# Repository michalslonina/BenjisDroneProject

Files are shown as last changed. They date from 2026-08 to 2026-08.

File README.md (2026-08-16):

# FPV Drone for Benjamin

A 3D printable FPV (First Person View) drone project designed for educational and recreational flying with my son Benjamin (age 9).

**Goal:** Build and fly a wireless-controlled 3D-printed drone using custom ESP32 firmware to learn about embedded systems, wireless communication, and flight control.

## 📚 Documentation (Start Here!)

1. **[FOR_BENJAMIN.md](docs/FOR_BENJAMIN.md)** — Benjamin's guide to the project
2. **[SYSTEM_DIAGRAM.md](SYSTEM_DIAGRAM.md)** — Visual system architecture (Mermaid diagrams)
3. **[SYSTEM_ARCHITECTURE.md](SYSTEM_ARCHITECTURE.md)** — How everything connects
4. **[BOM.md](BOM.md)** — Complete bill of materials with prices
5. **[SOURCING_GUIDE.md](SOURCING_GUIDE.md)** — Where to buy parts and timeline

## Project Structure

```
├── cad/                      # 3D models and CAD files
│   ├── frame/               # Drone frame components
│   ├── arms/                # Motor arms
│   └── body/                # Fuselage and housing
├── firmware/                 # Flight controller firmware
│   ├── esp32_transmitter/    # Xbox controller → RF transmitter
│   └── esp32_receiver/       # RF receiver → Flight controller
├── electronics/              # Circuit diagrams and PCB designs
├── docs/                     # Documentation
│   ├── FOR_BENJAMIN.md      # Benjamin's guide
│   ├── assembly/            # Assembly instructions
│   └── tuning/              # Betaflight configuration guide
├── slicing/                  # 3D printer settings and profiles
└── builds/                   # Build logs and flight test data
```

## System Overview

```
Xbox Controller → ESP32 TX ─(RF)─→ ESP32 RX → Flight Controller → Motors → 🚁 Flies!
                                      ↓
                                  FPV Camera → VTx ─(RF)─→ Phone (Goggles)
```

## Build Options

### ⭐ Option 1: Sub-250g FPV (RECOMMENDED)
- **Frame:** GoFlyPro 3" (38g, perfect for 250g limit)
- **Motors:** 1105 5000 KV lightweight (8g each)
- **Battery:** 2S 450mAh 45C (60g, ~4-5 min flight time)
- **Camera:** Caddx Baby Ratel (18g, 800 TVL)
- **VTx:** 25mW compact (10g, ~200m range)
- **Total Weight:** 200-250g ✅
- **Cost:** ~€65-100
- **Flight:** Agile, fun, good for indoors
- **See:** [SUB_250G_FPV_BUILD.md](SUB_250G_FPV_BUILD.md)

### Option 2: Standard 5" FPV
- **Frame:** TBS Source One (95-100g)
- **Motors:** 2300 KV brushless
- **Battery:** 3S 1000mAh
- **Camera:** 1000 TVL
- **VTx:** 200mW
- **Total Weight:** 350-400g
- **Cost:** ~€100-130
- **Flight:** Stable, longer flight time
- **See:** [WEIGHT_BUDGET.md](WEIGHT_BUDGET.md)

## Project Timeline

- **Week 1:** Order components (AliExpress + local)
- **Week 2-3:** Receive parts, begin 3D printing
- **Week 4-5:** Assembly and wiring
- **Week 5-6:** Firmware development (Benjamin's task)
- **Week 6+:** Testing, tuning, first flights

## Status

- [x] System design
- [x] Component selection & sourcing
- [ ] 3D frame design
- [ ] Component procurement
- [ ] Hardware assembly
- [ ] Firmware (receiver code)
- [ ] Betaflight configuration
- [ ] Testing & flight validation

## Safety

⚠️ **Before every flight:**
- Check all propellers are secure
- Verify battery connection
- Test control input
- Keep clear of people and animals
- Never aim at faces

## Learning Outcomes

✅ Wireless RF communication  
✅ Embedded systems programming (C/C++)  
✅ Flight dynamics and gyro/accelerometer sensors  
✅ Motor control and ESCs  
✅ 3D design and printing  
✅ Electronics assembly and soldering  
✅ Problem-solving and debugging  

---

## 🚀 START HERE

1. **[MASTER_BUILD_GUIDE.md](MASTER_BUILD_GUIDE.md)** ← Read this first! (Complete sourcing, assembly, testing)
2. **[SUB_250G_FPV_BUILD.md](SUB_250G_FPV_BUILD.md)** — Detailed sub-250g strategy
3. **[SYSTEM_DIAGRAM.md](SYSTEM_DIAGRAM.md)** — How everything connects
4. **[docs/FOR_BENJAMIN.md](docs/FOR_BENJAMIN.md)** — Benjamin's beginner guide

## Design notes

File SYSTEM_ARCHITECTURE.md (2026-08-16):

# FPV Drone System Architecture

## System Overview

This is a **wireless remote-controlled drone** where Benjamin controls it with an Xbox controller, and sees what the drone sees through FPV goggles on a phone.

### Block Diagram

```
┌─────────────────────────────────────────────────────────────┐
│                         GROUND (You & Benjamin)              │
├─────────────────────────────────────────────────────────────┤
│                                                               │
│  ┌──────────────┐         ┌─────────────┐                   │
│  │ Xbox         │         │ Old Phone   │                   │
│  │ Controller   │         │ (FPV        │                   │
│  │              │         │  Goggles)   │                   │
│  └──────┬───────┘         └──────▲──────┘                   │
│         │                        │                           │
│         │ USB Cable              │ WiFi/USB receiver         │
│         │                        │                           │
│  ┌──────▼──────────────────────────┐                        │
│  │    ESP32 TX                      │                        │
│  │  (Transmitter)                   │                        │
│  │  - Reads Xbox input              │                        │
│  │  - Sends stick data wirelessly   │                        │
│  └──────┬───────────────────────────┘                        │
│         │                                                     │
│         │ RF Signal (2.4GHz, ~100m range)                   │
│         │                                                     │
└─────────┼─────────────────────────────────────────────────────┘
          │
          │ (WIRELESS LINK)
          │
┌─────────▼─────────────────────────────────────────────────────┐
│                         DRONE (In the sky)                     │
├───────────────────────────────────────────────────────────────┤
│                                                                 │
│  ┌──────────────────┐         ┌─────────────────────┐         │
│  │ RF Module RX     │         │ FPV Camera + VTx    │         │
│  │ (Receiver)       │         │ (Video sender)      │         │
│  │ - Gets stick     │         │ - Sends video to    │         │
│  │   commands       │         │   phone goggles     │         │
│  └────────┬─────────┘         └─────────────────────┘         │
│           │                                                     │
│  ┌────────▼──────────────────┐                                │
│  │    ESP32 RX               │                                │
│  │  (Receiver)               │                                │
│  │  - Gets wireless commands │                                │
│  │  - Converts to FC signals │                                │
│  └────────┬──────────────────┘                                │
│           │                                                     │
│           │ SBUS Signal (serial signal)                       │
│           │                                                     │
│  ┌────────▼──────────────────┐                                │
│  │  Flight Controller (FC)    │                                │
│  │  - Reads stick commands    │                                │
│  │  - Controls motors         │                                │
│  │  - Stabilizes drone        │                                │
│  └────────┬──────────────────┘                                │
│           │                                                     │
│      ┌────┴────┬────────┬────────┐                            │
│      │          │        │        │                            │
│  ┌───▼──┐ ┌───▼──┐ ┌───▼──┐ ┌───▼──┐                        │
│  │Motor1│ │Motor2│ │Motor3│ │Motor4│                        │
│  └──────┘ └──────┘ └──────┘ └──────┘                        │
│     (ESCs drive each motor)                                   │
│                                                                 │
└─────────────────────────────────────────────────────────────────┘
```

## Data Flow

1. **Control Input** → Benjamin pushes Xbox sticks
2. **Wireless TX** → ESP32 sends stick positions via RF
3. **Wireless RX** → ESP32 on drone receives commands
4. **Flight Control** → Commands converted to motor speeds
5. **Video Output** → Camera sends video to phone (separate)

## Key Points for Benjamin

- **Two ESP32s talk to each other** using radio waves (2.4GHz)
- **Flight Controller** is like the drone's brain — it keeps everything balanced
- **Motors spin based on FC commands** — faster = drone goes up
- **Phone shows FPV camera view** — you see what the drone sees

## Safety Levels

```
Level 1: Sticks centered = Motors off (SAFE)
Level 2: Signal lost > 1 second = Motors stop (SAFE)
Level 3: Battery low = Soft landing procedure (SAFE)
```

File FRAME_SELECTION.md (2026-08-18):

# Frame Design Selection — FINAL DECISION

## Chosen Frame: ASCopter H-Frame (remixed for our build)

**Status:** ✅ Source downloaded, tuned, rendered, and verified. Ready to print.

**Files in this repo:** `cad/frame/`
- `ASCopterHframe.scad` — original source (by clifton2, Thingiverse thing:1758777, CC-BY-NC)
- `ASCopter_tuned.scad` — our tuned parameters, ready to open in OpenSCAD
- `ASCopter_tuned.stl` — pre-rendered STL, ready to slice

## Why This Frame

We evaluated 5 candidate OpenSCAD designs (Kestrel, kaefert's 250, FNQ220, mjholmes' mini quad, ASCopter H-Frame). Two were disqualified outright:

- **The Kestrel (Patshead/falcon-frames)** — turned out to be a **laser-cut carbon fiber design**, not 3D-printable. Ruled out immediately.
- **kaefert's "250" frame** — real OpenSCAD source checked line-by-line. Built for 5" props (`propeller_radius = 127/2`) with a full boxed enclosure for GPS, sonar, and OpenLog SD card — sensor gear we don't need. Heavy (thick walls, 24mm stack box) and would require gutting most of the design to fit our 3" sub-250g build. Not worth remixing.
- **mjholmes' mini quad** — designed around 1811 2900KV motors, 5" props, 15.5mm motor mount spacing. That's a completely different motor mount pattern than our 1103s (~9mm pattern). Would need a redesign, not a parameter tweak.

**ASCopter H-Frame** won because it's a lean, single flat-plate parametric design that already ships with a `motorType=20` ("1104") preset — nearly identical mount footprint to our 1103 motors (M2 screws, ~9mm hole spacing) — and every dimension (`quadWidth`, `quadLength`, `mainBodyWidth`, `bodyDepth`) is a top-level variable.

## Verified Tuning

Current values (this table has been corrected twice since the frame was first tuned — see the propeller collision note below for why):

| Parameter | Original default | Tuned value | Why |
|---|---|---|---|
| `motorType` | 13 (brushed) | **20** (1104 preset) | Closest match to our 1103 8000KV motors |
| `quadWidth` | 65mm | **110mm** | Left-right motor spacing; gives 33.8mm prop-tip clearance for 3" (76.2mm) props, widened later to fit the FC mounting pad (below) |
| `quadLength` | 65mm | **90mm** | Front-to-back (same-side) motor spacing; gives 13.8mm prop-tip clearance — see correction below |
| `mainBodyWidth` | 25mm | **36mm** | Matches F4V3S Plus flight controller mounting pattern with wall margin either side |
| `bodyDepth` | 2mm | 2mm (unchanged) | Thin plate keeps weight minimal |

**Verified weight:** Computed actual solid volume from the rendered STL → **~15.6g at 100% solid PETG**, realistically **~8-11g printed** with normal wall count + infill. That's dramatically lighter than the GoFlyPro 3" frame estimate (38g) we'd budgeted for earlier — this buys back real weight margin against the 250g limit.

### ⚠️ Corrected: propellers were overlapping (found via the assembly view)

`quadLength` was originally set to 70mm using the wrong math: I checked `quadWidth` (left-right motor spacing) against the propeller diameter correctly, but for `quadLength` I checked the frame's *total plate length* (90mm, including the rounded end caps) against the propeller diameter instead of the actual *motor-to-motor spacing*, which is `quadLength` itself (70mm) — 6.2mm short of the 76.2mm prop diameter. The front and rear propeller on each arm would have physically overlapped.

This wasn't caught until building `cad/assembly/full_assembly.scad` (see `cad/MOUNTING.md`) and looking at the top-down view with propeller placeholders included — the two circles visibly overlapped. Fixed by changing `quadLength` to 90mm, matching the margin `quadWidth` already had. **Lesson: check every motor-pair distance against the prop diameter, not just one axis, and check motor-to-motor distance specifically, not the plate's outer dimensions.**

## ⚠️ One thing to verify when motors arrive

The `motorType=20` mounting holes are laid out in a "+" cross pattern (holes 4.5mm from center along X/Y axes). Some 1103/1104 motors instead use a diagonal-square pattern. **When the 1103 motors arrive, measure the screw hole positions with calipers** and adjust `fixingRadius`/`fixingRadius2` in `ASCopter_tuned.scad` if needed — it's a two-number edit, not a redesign.

## Print Settings

Same general approach as the rest of the build:

```
Material: PETG (arms/plate are structural)
Layer height: 0.2mm
Infill: 15-20%, gyroid pattern
Supports: Not expected to be needed (flat plate design)
```

## How to Modify Further

Open `ASCopter_tuned.scad` in OpenSCAD (installed at `/Applications/OpenSCAD.app`). All tunable variables are at the top of the file — this is a good file for Benjamin to poke at once he's comfortable with the electronics, since changing a number and re-rendering is immediate visual feedback for learning parametric design.

## Component Mounting

The frame now has real cutouts for the flight controller stack (30.5×30.5mm pattern) and battery straps — see **[cad/MOUNTING.md](cad/MOUNTING.md)** for the full writeup, including the camera mount bracket we added and what's still unverified until real components are in hand.

---

*Superseded content: earlier drafts of this file discussed a 5" TBS Source One frame from before the sub-250g pivot — see git history if needed. Current build target remains the sub-250g 3" build described in [SUB_250G_FPV_BUILD.md](SUB_250G_FPV_BUILD.md).*

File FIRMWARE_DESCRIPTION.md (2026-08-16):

# Firmware Description (What the Code Will Do)

## Overview

Two ESP32 boards run firmware that talk to each other via radio (nRF24L01 modules). This document describes what each one does **in plain English** — Benjamin will write the actual code.

---

## ESP32 TX (Transmitter) - Ground Station

### Purpose
**Reads Xbox controller input and sends it wirelessly to the drone.**

### What It Does

1. **Reads Xbox Controller**
   - Connects via USB to the ESP32
   - Reads stick positions (left/right, up/down)
   - Reads button states (if we add buttons later)
   - Gets values every ~20ms (50 times per second)

2. **Prepares the Data**
   - Takes 4 stick values (throttle, pitch, roll, yaw) from Xbox controller
   - **Scales them to limit aggressive motor response**
     - Raw range: 0-255 (full power)
     - Limited range: 0-200 (80% max power)
     - This tames the 1104 7200 KV aggressive motors
   - Converts to numbers the flight controller understands
   - Packs them into a small message (4 bytes per stick)
   - Example: Xbox `[255, 127, 127, 127]` → limited `[200, 127, 127, 127]`
   - Benjamin can adjust limit in code (200, 210, 220, etc.) for tuning

3. **Sends via Radio**
   - Uses nRF24L01 to broadcast the stick data
   - Sends ~50 times per second (matches controller read rate)
   - Uses 2.4 GHz frequency (same as WiFi but different channel)
   - Range: ~100 meters in open air

4. **Error Handling**
   - Checks if radio module is connected
   - Logs errors to serial monitor (for debugging)
   - Keeps trying to send even if some packets are lost (radio is robust)

---

## ESP32 RX (Receiver) - On the Drone

### Purpose
**Receives wireless stick commands and converts them to flight controller signals.**

### What It Does

1. **Listens for Radio Signals**
   - Waits for packets from transmitter
   - Receives stick data every ~20ms
   - Checks if signal is valid (no corruption)
   - Tracks how long it's been since last valid signal

2. **Safety/Failsafe**
   - **If signal is good:** Passes stick values to flight controller
   - **If no signal for >1 second:** **IMMEDIATELY CUTS THROTTLE**
     - This is the most important safety feature
     - Prevents runaway drone if radio link dies
     - All sticks go to neutral/center position

3. **Converts to Flight Controller Format**
   - Flight controller expects **SBUS protocol** (a serial format)
   - Takes stick values like `[127, 200, 50, 150]`
   - Converts to SBUS packet (25 bytes, specific format)
   - Sends via UART serial port to flight controller

4. **Status Monitoring**
   - Blinks LED: 
     - **Fast blink** = Good signal, all OK
     - **Slow blink** = Signal weak or intermittent
     - **Off** = No signal / Failsafe active
   - Sends debug info to serial monitor

5. **Signal Quality Tracking**
   - Counts successful packets received
   - Measures RSSI (signal strength)
   - Reports back to ground station if we add telemetry later

---

## What Each Component Does (Firmware Perspective)

### Xbox Controller
- **Input device** — sends button/stick states via USB
- **Read every 20ms** — consistent update rate
- **Provides:** Throttle (0-255), Pitch (-128 to +127), Roll (-128 to +127), Yaw (-128 to +127)

### nRF24L01 RF Module
- **Wireless transceiver** — sends/receives radio packets
- **2.4 GHz frequency** — same as WiFi
- **Reliable but not perfect** — some packets may be lost (OK because we send 50/sec)
- **TX power:** Programmable (can set 0mW to 25mW for testing, or max for range)

### ESP32 TX (Transmitter)
- **Main job:** Read controller → format → send via radio
- **Updates:** 50 times per second
- **Protocol:** Custom binary format (4 bytes per stick, plus header/footer)

### ESP32 RX (Receiver)
- **Main job:** Listen for radio → validate → convert to SBUS → send to FC
- **Timing:** Receives packets as they arrive (async)
- **Failsafe:** Cut throttle if no signal for 1000ms
- **Output:** SBUS serial data at 100,000 baud

### Flight Controller
- **Input:** SBUS signal from ESP32 RX
- **Processing:** Reads stick commands, runs gyro stabilization, calculates motor speeds
- **Output:** PWM signals to ESCs (already happens, firmware doesn't control this)
- **Assumption:** Uses standard Betaflight firmware (pre-loaded before drone assembly)

### ESCs (Motor Speed Controllers)
- **Input:** PWM signal from Flight Controller
- **Job:** Convert PWM signal to motor commutation
- **Output:** 3-phase power to brushless motor
- **Assumption:** ESCs are already flashed and calibrated

### Motors
- **Input:** 3-phase AC power from ESCs
- **Job:** Spin proportional to power level
- **Output:** Mechanical thrust
- **Assumption:** No firmware involved (just physics)

---

## Data Flow Diagram (Firmware Perspective)

```
GROUND STATION:
┌──────────────────────────────────────┐
│ Xbox Controller                       │
│ (stick values: 0-255)                 │
└─────────────┬────────────────────────┘
              │
              ↓ USB read (20ms)
┌──────────────────────────────────────┐
│ ESP32 TX Firmware                     │
│ - Read USB device                     │
│ - Pack stick values into 4 bytes      │
│ - Send via nRF24L01                   │
└─────────────┬────────────────────────┘
              │
              ↓ nRF24L01 transmission
        [  RADIO LINK  ]
              ↓
┌──────────────────────────────────────┐
│ nRF24L01 RX                           │
│ (receives 4 bytes)                    │
└─────────────┬────────────────────────┘
              │
              ↓ SPI read (async)
┌──────────────────────────────────────┐
│ ESP32 RX Firmware                     │
│ - Receive radio packet                │
│ - Check for failsafe (1s timeout)     │
│ - Convert to SBUS (25 byte format)    │
│ - Send to UART @ 100k baud            │
│ - Blink LED for status                │
└─────────────┬────────────────────────┘
              │
              ↓ UART serial (to FC)
┌──────────────────────────────────────┐
│ Flight Controller (Betaflight)        │
│ (reads SBUS, runs stabilization)      │
└─────────────┬────────────────────────┘
              │
              ↓ PWM outputs (4 channels)
      [  ESC 1  ESC 2  ESC 3  ESC 4  ]
              │     │     │     │
              ↓     ↓     ↓     ↓
        [ Motor x4 spinning ]
              │     │     │     │
              ↓     ↓     ↓     ↓
            🚁 DRONE FLIES
```

---

## Communication Protocols

### USB (Xbox → ESP32 TX)
- **Standard USB HID protocol**
- **Baud rate:** Not applicable (USB is faster)
- **Data:** Stick positions + buttons
- **Benjamin's job:** Use existing USB library to read controller

### nRF24L01 (ESP32 TX ↔ ESP32 RX)
- **Custom binary protocol** (4 bytes per update)
- **Frequency:** 2.4 GHz (programmable channel)
- **Speed:** 1 Mbps
- **Packets:** ~20 bytes each
- **Timing:** Send every 20ms
- **Benjamin's job:** Learn nRF24L01 library, set up SPI bus, send/receive packets

### SBUS (ESP32 RX → Flight Controller)
- **Industry standard** for RC receivers
- **Baud rate:** 100,000
- **Format:** 25 bytes per frame
- **Frame structure:** 
  - Header byte: 0x0F
  - 11-bit channel data (16 channels possible, we use 4)
  - Footer/sync bytes
- **Benjamin's job:** Format stick values into SBUS packets, send via UART

---

## Key Implementation Decisions

### Why SBUS?
- Standard protocol used by all Betaflight flight controllers
- Easy to implement once you understand the format
- Much more reliable than PWM (parallel channels)

### Why Custom RF Protocol?
- nRF24L01 doesn't care about data format
- Simple 4-byte stick format is fast and reliable
- Can easily add telemetry later (battery voltage, signal strength, etc.)

### Why 50 Hz (20ms) update rate?
- Standard for radio control systems
- Fast enough for smooth control
- Slow enough to not overload microcontroller or radio

### Why 1-second failsafe?
- Enough time to distinguish signal loss from temporary glitch
- Prevents rapid oscillations
- Standard in RC systems

---

## Testing the Firmware

Benjamin can test each part separately:

1. **Xbox Controller** — Read values, print to serial monitor
   - "Throttle: 127, Pitch: 200, Roll: 50, Yaw: 150"

2. **nRF24L01 TX** — Send packets, print "Sent OK" or "Failed"
   - Add counters: "Sent 1234 packets, 0 lost"

3. **nRF24L01 RX** — Receive packets, print received values
   - "RX: 127, 200, 50, 150" every 20ms

4. **SBUS Conversion** — Show SBUS bytes being sent
   - Print hex values: "0x0F 0xAA 0xBB 0xCC ..."

5. **Failsafe** — Disconnect radio, count down to failsafe trigger
   - "Signal OK" → "Lost 0.5s" → "Lost 1.0s" → "FAILSAFE"

---

## Debugging Tools

Benjamin will use these to debug when things don't work:

1. **Serial Monitor** (USB to computer)
   - Shows debug messages at 115,200 baud
   - Can see what firmware is doing every step

2. **LED Blink Patterns**
   - Visual feedback even without serial connection
   - Tells you if radio is working

3. **Oscilloscope** (optional, if Dad has one)
   - Can measure SBUS signal to see if format is correct
   - Can measure nRF24L01 SPI bus

4. **Test Flight Checklist**
   - Check each stick in Betaflight (configurator app)
   - Watch motor speeds on FC before propellers attached

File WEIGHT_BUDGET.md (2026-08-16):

# Weight Budget - Staying Under 250g

## Challenge

Standard FPV quad components are heavier than 250g total. To stay under this limit for a 9-year-old's beginner drone, we need to **optimize component selection and print settings**.

---

## Weight Budget Breakdown

### Target: **250g Total Maximum**

| Component | Standard | Optimized | Notes |
|---|---|---|---|
| **FRAME** | 120g | 95-100g | 3D printed PETG, 15% infill |
| **MOTORS** (4x) | 120g | 100-110g | 2200-2300 KV brushless, lightweight |
| **ESCs** (4x) | 48g | 40-45g | 20A, aluminum PCB (lighter) |
| **Flight Controller** | 12g | 8-10g | F4 compact (smaller = lighter) |
| **Camera** | 20g | 15-18g | Lightweight CMOS 800-1000TVL |
| **VTx** | 15g | 12-14g | Compact 200mW module |
| **Battery** (3S) | 120g | 90-100g | **1000mAh → 750mAh** (sacrifice flight time) |
| **Propellers** (2 sets) | 20g | 15-18g | Plastic props, lightweight |
| **Wiring/Connectors** | 35g | 25-30g | Minimize wire gauge, use lightweight connectors |
| **Misc** (camera mount, tape, velcro) | 20g | 15-18g | Minimize hot glue, use velcro |
| | | | |
| **TOTAL** | **530g** | **375-400g** | **Still Over 250g** ⚠️ |

---

## The Real Situation

**Honest assessment:** A fully functional FPV drone with video transmission **cannot realistically stay under 250g** with standard components.

### Why?
- **3S Battery alone:** 100-120g (required for reasonable flight time)
- **4 Motors:** 100-110g minimum
- **Frame:** 80-100g
- **Everything else:** 50-70g
- **Sum:** ~330-400g minimum

### What We Have Options

## Option 1: Accept ~350-400g (Recommended)

This is still **beginner-friendly** and **practical**.

| Category | Weight | Notes |
|---|---|---|
| Frame (PETG, 15% infill) | 95g | Lightweight but strong |
| Motors (2300 KV, ~26g ea) | 104g | Standard beginner motors |
| ESCs (20A, ~11g ea) | 44g | Budget options available |
| FC (F4 compact) | 9g | |
| Camera (1000TVL) | 17g | Decent video quality |
| VTx (200mW) | 13g | Good range |
| Battery (3S 1000mAh, 30C) | 110g | Reasonable flight time (4-6 min) |
| Propellers | 18g | 2 sets |
| Wiring/misc | 28g | |
| **TOTAL** | **438g** | Heavier but practical |

**Result:** Drone will fly well, but battery life is ~4-6 minutes per charge.

---

## Option 2: Lightweight Setup (~300g)

Sacrifice flight time for weight:

| Category | Weight | Notes |
|---|---|---|
| Frame (PLA, 10% infill) | 85g | Lighter but more fragile |
| Motors (2200 KV lighter) | 95g | Specifically lightweight variants |
| ESCs (aluminum, 20A) | 40g | Higher quality = lighter |
| FC (F4 compact) | 8g | Smallest available |
| Camera (lightweight 600TVL) | 14g | Lower res but lighter |
| VTx (compact 25mW) | 10g | Lower power = lighter, shorter range |
| Battery (2S 500mAh, 45C) | 70g | **2S = less power, flies slower** |
| Propellers (light plastic) | 14g | Minimal thickness |
| Wiring/misc | 20g | Minimal wire |
| **TOTAL** | **356g** | Still over 250g, but optimized |

**Result:** Barely faster than 250g, compromises too much performance. **Not recommended.**

---

## Option 3: Micro Quad (Actually Under 250g)

Go completely different direction — **2-3 inch brushless micro quad**:

**Pros:**
- ✅ Can actually stay under 250g
- ✅ Safe for indoors
- ✅ Cheap components
- ✅ Fast and fun

**Cons:**
- ❌ Less stable (harder for beginner)
- ❌ Shorter flight time (2-3 min)
- ❌ Less impressive flying
- ❌ Harder to do FPV well (small frame)
- ❌ Less room for 3D printing learning

**Example micro quad (~200g):**
- 3" frame: 40g
- 4x 1104 motors (17g ea): 68g
- 4x 6A ESCs: 20g
- Tiny FC: 5g
- Micro camera: 8g
- Micro VTx: 8g
- 2S 300mAh battery: 40g
- Propellers: 8g
- Total: ~197g ✅

---

## Recommendation for Benjamin

**Go with Option 1 (~350-400g total)** because:

✅ **Practical performance** — Flies well, beginner-friendly  
✅ **Better learning** — Room for larger 3D-printed parts  
✅ **More impressive** — Better range with FPV video  
✅ **More durable** — PETG frame can handle crashes  
✅ **Better flight time** — 4-6 minutes per battery  
✅ **Honest scope** — Know upfront weight is ~350-400g  

The drone will still be **lightweight** and **fast enough for a 9-year-old** to enjoy.

---

## How to Minimize Weight

If you really want to get as close to 250g as possible:

### 3D Printing Optimization
```
Settings to reduce weight:
- Layer height: 0.2mm (no reduction, affects strength)
- Infill: 10-12% (vs 15-20%)
  • Use gyroid pattern (strongest at low infill)
  • Saves ~10-15g on frame
- Wall thickness: 2-3 layers (vs 3-4)
  • Saves ~8-12g
- Supports: Tree supports (less material)
  • Saves ~5-10g
- Material: Use PLA instead of PETG
  • Saves ~15-20g but LESS durable

Total savings from printing: ~30-50g
```

### Component Selection
- **Lightest 2300 KV motors:** ~25g each (vs 30g)
- **Aluminum PCB ESCs:** ~10g each (vs 12g)
- **Compact F4 FC:** ~8g (vs 12g)
- **Low-power VTx:** ~10g at 25mW (vs 15g at 200mW)
  - *Trade-off: ~50m range instead of 500m*
- **Smaller battery:** 750mAh (vs 1000mAh)
  - *Trade-off: 3-4 min flight time instead of 5-6 min*

**Maximum weight reduction: ~50-70g**  
**New total: ~370-380g**

Still over 250g, but this is realistic.

---

## Honest Assessment

**You cannot have all of these with a 250g budget:**
- FPV camera + video TX (adds ~30g)
- Decent flight time (1000mAh battery = ~110g)
- Stable flight (4+ motors and frame)
- 5-inch props (larger = more stable)

**Trade-off decisions:**
1. **Keep FPV** — go to ~350-400g
2. **Stay under 250g** — remove FPV camera, go micro quad
3. **Compromise** — use only recording camera, no live video (saves ~12g)

---

## Recommendation

**Build at ~350-400g with good components** instead of struggling to hit 250g with compromised parts.

Benjamin will have:
- ✅ A drone that actually flies well
- ✅ FPV video to see what the drone sees
- ✅ Enough power for interesting flights
- ✅ Room to learn and improve

vs.

- ❌ A 250g drone with weak motors
- ❌ Barely-controllable micro quad
- ❌ 2-minute flight times
- ❌ Frustration instead of fun

**Proceed with the standard build (~350-400g).** It's still lightweight, fast, and perfect for a beginner!

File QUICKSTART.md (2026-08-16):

# Quick Start Guide - FPV Drone Project

Welcome! This guide helps you get started with Benjamin's drone project. Read this first, then follow the detailed docs.

---

## What Are We Building?

A **wireless 3D-printed FPV drone** that Benjamin controls with an Xbox controller. The drone sends back a live camera feed so he can see what it sees.

**Key components:**
- 3D-printed frame (you'll print this)
- Brushless motors + ESCs (you'll solder)
- Flight controller (pre-programmed)
- Custom wireless receiver/transmitter (Benjamin will code this)
- FPV camera + video transmitter
- 3S LiPo battery

---

## What Benjamin Will Learn

✅ **Programming (C/C++)** — Write ESP32 firmware  
✅ **Wireless comms** — How RF modules talk  
✅ **Electronics** — Soldering, wiring, power distribution  
✅ **Mechanics** — 3D design, assembly, troubleshooting  
✅ **Embedded systems** — Microcontroller real-time control  
✅ **Flying** — FPV piloting and drone stability  

---

## Timeline Overview

```
Week 1:    Order parts → Start 3D printing
Week 2-3:  Parts arrive → Continue printing + assembly prep
Week 4-5:  Final assembly → Wiring + electronics
Week 5-6:  Benjamin writes firmware → Testing & tuning
Week 6+:   First flights! 🚁
```

---

## Quick Read Order

**For Dad (setup):**
1. [BOM.md](BOM.md) — What to buy (~€100)
2. [SOURCING_GUIDE.md](SOURCING_GUIDE.md) — Where to buy it
3. [FRAME_SELECTION.md](FRAME_SELECTION.md) — Which 3D model to print

**For Benjamin (learning):**
1. [docs/FOR_BENJAMIN.md](docs/FOR_BENJAMIN.md) — Your project overview
2. [SYSTEM_DIAGRAM.md](SYSTEM_DIAGRAM.md) — How everything connects
3. [SYSTEM_ARCHITECTURE.md](SYSTEM_ARCHITECTURE.md) — Deep dive into each part

**For Assembly (both):**
1. [docs/ASSEMBLY_GUIDE.md](docs/ASSEMBLY_GUIDE.md) — Step-by-step assembly
2. [FIRMWARE_DESCRIPTION.md](FIRMWARE_DESCRIPTION.md) — What Benjamin's code will do

**For First Flight:**
1. [docs/TESTING_CHECKLIST.md](docs/TESTING_CHECKLIST.md) — Pre-flight tests

---

## The Next 3 Actions (Start Today)

### Action 1: Order Components (This Week)

**Go to [SOURCING_GUIDE.md](SOURCING_GUIDE.md) and order:**

- [ ] **AliExpress items** (20-30 day delivery)
  - nRF24L01 RF modules (2x)
  - Brushless motors (4x)
  - ESCs (4x)
  - Flight controller
  - Camera + VTx
  - Video receiver
  - Connectors + wire
  - **Total:** ~€80-100

- [ ] **Local hobby shop items** (5-10 day delivery)
  - 3S LiPo battery
  - Battery charger
  - Propellers
  - **Total:** ~€30-40

### Action 2: Start 3D Printing (This Week)

**From [FRAME_SELECTION.md](FRAME_SELECTION.md):**

- [ ] Find an open-source 5" quad frame on Printables/Thingiverse
- [ ] Download STL files
- [ ] Prepare print settings for Ender 5 Plus
- [ ] Start printing frame parts in parallel on all 3 printers
- [ ] Target: Have frame ready by week 3

### Action 3: Study the System (This Week)

**For Benjamin:**
- [ ] Read [docs/FOR_BENJAMIN.md](docs/FOR_BENJAMIN.md) (15 min)
- [ ] Look at [SYSTEM_DIAGRAM.md](SYSTEM_DIAGRAM.md) (20 min)
- [ ] Understand what each part does

**For Dad:**
- [ ] Read [SYSTEM_ARCHITECTURE.md](SYSTEM_ARCHITECTURE.md) (30 min)
- [ ] Understand the data flow
- [ ] Plan assembly steps

---

## Budget Breakdown

| Category | Cost | Notes |
|---|---|---|
| **Electronics** | ~€100 | Motors, ESCs, FC, camera, VTx, receiver |
| **Filament** | ~€20-30 | For 3D printing frame (you have) |
| **Charger** | ~€10-15 | If you don't have one |
| **Misc** | ~€10-15 | Connectors, solder, hot glue |
| | | |
| **TOTAL** | ~€150-160 | Can reduce to €100-120 with discounts |

---

## Tools You'll Need

**Soldering:**
- 30-40W soldering iron ✓
- Solder (lead-free or regular) ✓
- Helping hands tool ✓
- Wet sponge (for iron cleaning) ✓

**Mechanical:**
- Screwdrivers (0.5mm, 1.5mm, 2.5mm) ✓
- Flush cutters ✓
- Hot glue gun ✓
- Super glue (cyanoacrylate) ✓
- Sandpaper (120/220/400 grit) ✓

**Electrical:**
- Multimeter ✓
- USB cables ✓
- Servo extension cables ✓

**Software:**
- Arduino IDE (free) — for programming ESP32
- Betaflight Configurator (free) — for FC setup
- FPV app on old phone — for goggles

---

## Key Concepts for Benjamin

### What is FPV?
**FPV = First Person View**  
You see from the drone's perspective, like you're riding on it!

### How does control work?
```
You move Xbox sticks → Radio signal → Drone receives → Motors spin → Drone flies
```

### What's the WiFi module?
The **nRF24L01** is like a tiny radio tower.  
It sends your stick commands wirelessly to the drone. Same frequency as WiFi but different.

### Why two ESP32s?
- **One on ground** (with Xbox controller) — Transmitter
- **One on drone** — Receiver
- They talk to each other via radio

### What is the Flight Controller?
The **drone's brain**.  
It reads your commands and automatically balances the drone using gyro sensors.

---

## Safety First!

⚠️ **Rules for flying:**
1. Never fly near people or animals
2. Always remove propellers when testing
3. Check battery voltage before flying
4. Let propellers cool between flights
5. Wear eye protection (just in case!)
6. Have a safe open area (park, large field)
7. Never point drone at faces
8. Always do preflight checks

---

## If Something Goes Wrong

**Don't panic!** Troubleshooting is part of learning.

| Problem | Likely Cause | Solution |
|---|---|---|
| Won't power on | Low battery | Charge battery |
| Radio won't connect | nRF24 not working | Check SPI wires, power |
| Motors won't spin | Soldering problem | Check solder joints |
| Gyro reading wrong | FC oriented wrong | Rotate FC in software |
| Drone crashes | Prop came off | Tighten propellers |

**When stuck:**
1. Check the relevant troubleshooting section
2. Use multimeter to test connections
3. Ask Dad for help
4. Worst case: Start over (you have spare parts!)

---

## Next Steps (Right Now)

1. **Read this file completely** (you're doing it!)
2. **Open [SOURCING_GUIDE.md](SOURCING_GUIDE.md)** and order parts
3. **Open [FRAME_SELECTION.md](FRAME_SELECTION.md)** and start 3D printing
4. **Create a reminder** to check AliExpress order status
5. **Show Benjamin** [docs/FOR_BENJAMIN.md](docs/FOR_BENJAMIN.md) this weekend

---

## Success Metrics

By the end of this project, Benjamin will have:

✅ Soldered and assembled a complete FPV drone  
✅ Written firmware to control it wirelessly  
✅ Flown it successfully indoors and/or outdoors  
✅ Fixed bugs when things didn't work  
✅ Understood how drones really work (not just "it flies")  
✅ Built something truly cool with his dad! 🚀

---

## Contact & Help

When you get stuck:
- YouTube search for specific component (e.g., "nRF24L01 Arduino tutorial")
- Check [docs/TESTING_CHECKLIST.md](docs/TESTING_CHECKLIST.md) for troubleshooting
- Ask in FPV community forums (DIYDrones, RCGroups)
- Reach out to local maker/hobby communities

---

## You're Ready!

You have everything you need to build this drone. The hardest part is starting.

**Let's build something awesome!** 🚁✨

Start with [SOURCING_GUIDE.md](SOURCING_GUIDE.md) — Order parts now, everything else flows from there.

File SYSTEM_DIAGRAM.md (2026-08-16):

# System Diagram - Mermaid

## High-Level System Diagram

```mermaid
graph TB
    subgraph Ground["🟩 GROUND STATION (You & Benjamin)"]
        Xbox["Xbox Controller"]
        Phone["Old Phone with FPV App"]
        TX["ESP32 TX<br/>(Radio Transmitter)"]
        
        Xbox -->|USB Cable| TX
        RX_Signal["📡 RF Signal<br/>2.4 GHz"]
    end
    
    subgraph Drone["🟦 DRONE (In the Sky)"]
        RX["ESP32 RX<br/>(Radio Receiver)"]
        FC["Flight Controller<br/>(Drone's Brain)"]
        Motors["4x Brushless Motors<br/>with ESCs"]
        Camera["FPV Camera"]
        VTx["VTx<br/>(Video TX)"]
        
        RX -->|SBUS Signal| FC
        FC -->|Speed Commands| Motors
        Camera -->|Video Signal| VTx
        Video_Signal["📡 Video Signal<br/>5.8 GHz"]
    end
    
    TX -->|"2.4 GHz RF"| RX
    VTx -->|"5.8 GHz RF"| Phone
    
    Phone -->|FPV View| Ground
    
    style Ground fill:#90EE90,stroke:#333,stroke-width:2px
    style Drone fill:#87CEEB,stroke:#333,stroke-width:2px
    style RX_Signal fill:#FFD700,stroke:#333,stroke-width:1px
    style Video_Signal fill:#FFD700,stroke:#333,stroke-width:1px
```

## Control Flow Diagram

```mermaid
graph LR
    A["🎮 Benjamin<br/>Pushes Sticks"] 
    B["Xbox Controller<br/>Reads Input"]
    C["ESP32 TX<br/>Converts to RF"]
    D["📡 Radio Waves<br/>2.4 GHz"]
    E["ESP32 RX<br/>on Drone"]
    F["Flight Controller<br/>Reads Commands"]
    G["Motors Spin<br/>at Different Speeds"]
    H["🚁 Drone Moves!"]
    
    A --> B
    B --> C
    C --> D
    D --> E
    E --> F
    F --> G
    G --> H
    
    style A fill:#FFB6C1
    style D fill:#FFD700
    style H fill:#90EE90
```

## Data Signal Types

```mermaid
graph TD
    subgraph Signals["Types of Signals in This System"]
        A["🟦 CONTROL SIGNAL<br/>Stick positions<br/>2.4 GHz RF<br/>100m range"]
        
        B["🟩 POWER SIGNALS<br/>Motor speeds<br/>PWM/SBUS<br/>Very short distance"]
        
        C["🟪 VIDEO SIGNAL<br/>Camera feed<br/>5.8 GHz RF<br/>100-200m range"]
    end
    
    style A fill:#87CEEB
    style B fill:#90EE90
    style C fill:#DDA0DD
```

## Component Connections

```mermaid
graph TB
    subgraph Electronics["All the Electronics"]
        ESP32RX["ESP32 RX<br/>3.3V Logic"]
        FC["Flight Controller<br/>5V Logic"]
        LLC["Logic Level<br/>Converter"]
        
        ESP32RX -->|3.3V SBUS| LLC
        LLC -->|5V SBUS| FC
    end
    
    subgraph Power["Power Distribution"]
        Battery["3S LiPo Battery<br/>12.6V max"]
        BEC["BEC on ESC<br/>5V regulated"]
        
        Battery --> BEC
        BEC --> FC
        BEC --> Electronics
    end
    
    subgraph Motors["Motor Control"]
        FC -->|Speed 1| ESC1["ESC 1"]
        FC -->|Speed 2| ESC2["ESC 2"]
        FC -->|Speed 3| ESC3["ESC 3"]
        FC -->|Speed 4| ESC4["ESC 4"]
        
        ESC1 --> M1["Motor 1"]
        ESC2 --> M2["Motor 2"]
        ESC3 --> M3["Motor 3"]
        ESC4 --> M4["Motor 4"]
    end
    
    style Battery fill:#FFB6C1
    style FC fill:#90EE90
    style Motors fill:#87CEEB
```

## Simplified Benjamin's View

```mermaid
graph TB
    YOU["🎮 You Push Sticks"]
    MAGIC1["✨ Magic Messenger #1<br/>Sends command to drone"]
    MAGIC2["✨ Magic Messenger #2<br/>Receives on drone"]
    BRAIN["🧠 Drone's Brain<br/>Figures out what to do"]
    MUSCLES["💪 4 Motors<br/>Spin at right speeds"]
    FLY["🚁 Drone Flies!"]
    
    YOU --> MAGIC1
    MAGIC1 -->|Radio Waves| MAGIC2
    MAGIC2 --> BRAIN
    BRAIN --> MUSCLES
    MUSCLES --> FLY
    
    YOU -->|"You Also See<br/>Camera Video"| SEE["👁️ Eyes<br/>Phone Screen"]
    
    style YOU fill:#FFB6C1
    style MAGIC1 fill:#FFD700
    style MAGIC2 fill:#FFD700
    style BRAIN fill:#90EE90
    style MUSCLES fill:#87CEEB
    style FLY fill:#00FF00,color:#000
    style SEE fill:#DDA0DD
```

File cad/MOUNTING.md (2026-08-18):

# Component Mounting — Frame, Camera, VTx, Battery, Flight Controller

## What we checked

Before this, the frame (`cad/frame/`) was a bare motor-mount plate — no dedicated
holes or brackets existed anywhere in the project for the flight controller stack,
camera, VTx, or battery. The docs (BOM.md, MASTER_BUILD_GUIDE.md) *mentioned*
printing a "camera mount" and "battery strap" but no actual design ever existed.
This is now fixed for FC + battery (built into the frame itself) and camera
(dedicated bracket added). VTx rides on the FC mount — see below for why.

**See the whole thing assembled:** `cad/assembly/full_assembly.scad` combines the
real frame + camera mount STLs with placeholder geometry (motors, propellers,
FC/PDB/VTX stack, battery, camera body) so you can see the full layout in one
file. Open it in OpenSCAD. Rendering it is what caught a real problem below.

## Orthogonal views (color-coded by component)

| View | File | Shows |
|---|---|---|
| Top | `cad/assembly/assembly_top.png` | Prop clearance, overall footprint |
| Front | `cad/assembly/assembly_front.png` | Left-right motor spread, stack height |
| Side | `cad/assembly/assembly_side.png` | Front-to-back length, battery overhang, camera tilt |

Color legend: frame = gold, motors = black, propellers = translucent blue,
PDB = firebrick red, FC = forest green, VTX = navy, standoffs = silver,
battery = orange, camera mount = dark gray.

**Fit check result:** this took two rounds. The first round (below, items 1-2)
looked thorough at the time but missed three real problems that a second,
more careful pass caught — noted here so the same mistakes aren't repeated.

**Round 2 — caught by actually eyeballing the rendered views closely, not just
checking the specific thing I'd just changed:**

3. **Propellers were genuinely colliding**, not just close — a real bug in
   `cad/frame/ASCopter_tuned.scad` itself, not the visualization. `quadLength`
   (70mm) was checked against the prop diameter using the wrong distance (the
   plate's total length, not the actual motor-to-motor spacing, which IS
   `quadLength`). Real motor spacing was 70mm against a 76.2mm prop diameter —
   a 6.2mm overlap. Fixed by changing `quadLength` to 90mm in the real frame
   file (see FRAME_SELECTION.md for the corrected table) and re-rendering the
   actual printable STL, not just the assembly view.
4. **The camera looked disconnected from its mount** — the camera placeholder
   cube was positioned at a Z height picked to "look about right" rather than
   computed from the mount's actual stacked height, so it partially overlapped
   the mount body instead of resting on top of it. Fixed by computing
   `cam_mount_top_z` from the mount's real measured part heights and placing
   the camera's pivot exactly on that surface (`camera_assembly()` in
   `full_assembly.scad`), then verifying contact with a tight zoomed render.
5. **The battery collided with the FC/PDB/VTX stack** — 16.25mm of overlap.
   The battery placeholder had been centered on the real frame's strap-slot
   position (`batteryZoneCenterY`, a small feature meant for a thin strap, not
   the battery's own center), without checking the battery box's full 60mm
   length against the FC pad boundary. Fixed by computing the battery's center
   directly from the FC pad's edge plus a clearance gap, instead of reusing
   the strap-slot coordinate.

**Round 1 — the two things checked before this round, both fine on
re-verification:**

1. The camera mount's first two placements (3mm past the motor center, then
   20mm past the frame edge) both still overlapped the arm and/or the FC stack
   standoffs — visible directly in the top and side renders as overlapping
   geometry. The mount's actual shape (an asymmetric clamp) reaches further
   toward the frame than its bounding box suggested. Fixed by pushing it 30mm
   past the frame edge (this distance held up in round 2 as well).
2. A low-res top-view thumbnail made the camera mount look like it was
   overlapping the propeller disc — checked with the actual numbers (mount
   footprint vs. prop swept radius) and a zoomed re-render: there's ~10-30mm
   of real clearance. Still holds after the quadLength fix.

**Takeaway:** verifying "the thing I just changed" isn't the same as verifying
the whole assembly. Round 1 confirmed the camera mount didn't hit the frame or
the propellers, but never checked propeller-vs-propeller, camera-vs-mount
attachment, or battery-vs-stack — three different pairs of parts nobody had
looked at together yet.

## Flight Controller / PDB / VTx — built into the frame

The F4V3S Plus bundle is sold as a "flytower" stack: FC, PDB, and VTx are separate
boards that bolt together vertically on 4 standoffs, all sharing the same
**30.5×30.5mm** hole pattern (confirmed via board specs: ~36×36mm board, 30.5mm
mount spacing). Because they stack on common standoffs, only the *bottom* of the
stack needs new holes cut into the frame — we don't need a separate VTx mount.

`cad/frame/ASCopter_tuned.scad` now cuts:
- A 30.5×30.5mm hole pattern (`fcMountSpacing`), centered on the plate, sized for
  M3 screws (`fcMountHoleRadius = 1.6mm` clearance)
- A clean flat pad around those holes (`fcPadMargin`) — the weight-saving hex grid
  is explicitly excluded from this zone so the stack has a solid, flat seat
  instead of resting on a fused/uneven cutout pattern

**⚠️ Verify before printing:** the search result describing the 30.5mm pattern
mentioned "M4 holes," which is unusual for this board class (M3 is standard for
30.5mm-pattern mini stacks). Measure the actual board's screw holes with calipers
when it arrives and adjust `fcMountHoleRadius` if needed.

You'll need 4× M3 nylon standoffs (length depends on stack height — start with
20-25mm, adjust once you have the boards in hand) to actually build the stack up
from the frame.

## Battery — strap slots built into the frame

Two slots (`batteryStrapSlotWidth/Length/Spacing`) are cut into the front zone of
the plate, between the front motor arms and the FC pad. A velcro/hook-and-loop
strap threads up through one slot, over the battery, and down through the other.

**⚠️ Verify before printing:** slot spacing (currently 14mm apart) was sized to
fit the available space on this small plate, not measured against the actual
850mAh 2S battery footprint. Once the battery arrives, check whether the strap
geometry actually holds it securely — the battery may need to sit slightly
forward of the plate's front edge, which is normal on micro builds this size.

## Camera — dedicated bracket added

`cad/body/Cam_Mount_Plate.stl` + `cad/body/Cam_Mount_Base.stl` — a two-piece
"universal" FPV camera mount (originally by MultiRC, Thingiverse thing:1110726),
clamped with a single M3 screw so it fits basically any small FPV camera,
adjustable to any tilt angle.

- Verified via STL bounding box: Plate is 21.5×31.7×13.5mm, Base is
  19.6×12.5×8.0mm — both comfortably smaller than our frame
- Verified weight: ~3.5g combined at 100% solid, realistically ~2-3g printed
- The F4V3S Plus bundle's camera measures 28×26×28mm — the mount's clamp should
  fit this, but **test-fit it before committing to final assembly**; this design
  isn't parametric (no OpenSCAD source was published, only STL), so it can't be
  resized in software if it doesn't fit — only filed/sanded by hand

**⚠️ Not yet solved:** how this bracket physically attaches to the ASCopter frame
(screw, zip-tie, or glue) hasn't been verified — the frame's small 4mm holes
along the plate edges (`mountingPostHoleRadius`) are sized for zip-ties and are
the most likely attachment point, but confirm this once both parts are in hand.

## Summary of what's now in `cad/`

```
cad/
├── frame/
│   ├── ASCopterHframe.scad      — original upstream source
│   ├── ASCopter_tuned.scad      — our tuned version (motor mount, FC pad, battery slots)
│   ├── ASCopter_tuned.stl       — pre-rendered, ready to slice
│   └── frame_preview.png        — top-down render for reference
├── body/
│   ├── Cam_Mount_Plate.stl      — camera mount, frame-side piece
│   └── Cam_Mount_Base.stl       — camera mount, clamp piece
├── assembly/
│   ├── full_assembly.scad       — everything combined, for visualizing the whole build
│   └── assembly_preview.png     — rendered snapshot
└── arms/                         — empty; ASCopter's arms are integral to the frame plate, not separate parts
```

## Found while building the assembly view

Putting everything in one file surfaced a real spatial conflict, not just a
rendering bug: real 850mAh 2S batteries run 52-75mm long (checked against
Tattu/RoaringTop/CNHL specs), but the front zone we carved the battery straps
into is only ~27mm deep. Even the shortest realistic battery overhangs this
frame's edge — that's normal for a build this small, but it means the battery
and the camera mount **cannot go on the same end** of the frame, or they'll
collide. `full_assembly.scad` now places them on opposite ends deliberately.
Keep this in mind if you ever revisit the battery strap slot position in
`ASCopter_tuned.scad` — it needs to stay on the end away from the camera.

## Still open

- VTx mount: assumed to ride on the FC stack standoffs (see above) — confirm once
  the F4V3S Plus bundle arrives and you can see its actual board layout
- Camera mount attachment method to the frame: not yet decided (see above)
- FC mount screw size (M3 assumed, "M4" mentioned in one source): verify with calipers
- Battery strap slot spacing: verify against actual battery footprint, and note
  the battery will overhang the frame edge on the strap side — expected, not a defect
- `full_assembly.scad` uses estimated placeholder dimensions for everything except
  the frame and camera mount (which are real STLs) — swap in real models/measurements
  as parts arrive and get measured with calipers

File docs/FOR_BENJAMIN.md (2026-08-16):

# Welcome Benjamin! Your FPV Drone Project Guide

Hi Benjamin! 👋 This is YOUR drone project. You're going to build and control a drone that flies and lets you see what it sees!

## What Does Each Part Do?

### The Controller (Xbox Controller)
This is how you **tell the drone what to do**. When you push the sticks:
- **Left stick up/down** = Throttle (how fast the motors spin)
- **Left stick left/right** = Rotation (makes drone spin)
- **Right stick up/down** = Pitch (drone goes forward/backward)
- **Right stick left/right** = Roll (drone goes left/right)

### The Radio Transmitter (ESP32 TX)
This is like a **magic messenger**. It takes your controller inputs and sends them through the air to the drone using invisible radio waves. It's the same type of radio waves your WiFi uses!

### The Drone Receiver (ESP32 RX)
This is the **magic messenger on the drone**. It catches the radio signal from the transmitter and tells the flight controller what to do.

### The Flight Controller (FC)
This is the **drone's brain**. It reads your commands and figures out how fast each motor should spin to:
- Keep the drone balanced
- Fly forward/backward
- Turn left/right
- Go up/down

It does this **hundreds of times per second**!

### The Motors
These are the **drone's muscles**. The flight controller tells each one how fast to spin. Four motors spinning at different speeds = drone moves!

### The Camera & Video Transmitter (VTx)
The camera is the **drone's eyes**. The VTx is the **radio broadcaster**. They work together to send video to your phone so you can see what the drone sees while flying!

## How It All Works Together

```
You push sticks on Xbox
           ↓
ESP32 TX gets the signal
           ↓
Sends radio signal to drone
           ↓
ESP32 RX on drone receives it
           ↓
Flight Controller reads commands
           ↓
Flight Controller tells motors how fast to spin
           ↓
Motors spin → Drone flies!
           ↓
Camera sees everything
           ↓
VTx sends video to your phone
           ↓
You see FPV (First Person View)!
```

## Your Jobs (With Dad's Help)

1. **Learn about each part** — Know what it does
2. **Help assemble** — Put pieces together (mechanical)
3. **Write the firmware** — Tell the ESP32 RX what to do (coding!)
4. **Test and fly** — Make sure everything works

## Safety Rules

⚠️ **BEFORE EVERY FLIGHT:**
- Check that all propellers are tight
- Make sure battery is connected
- Check radio signal is good
- Keep people and pets away from propellers
- Never point drone at faces

⚠️ **IF YOU LOSE CONTROL:**
- Let go of sticks (motors stop)
- The drone will turn off motors to be safe

## Cool Things You'll Learn

✅ Radio signals and wireless communication  
✅ How drones stay balanced (gyros and sensors)  
✅ Embedded systems and microcontrollers  
✅ C/C++ programming  
✅ Soldering and electronics assembly  
✅ Problem-solving when things don't work  
✅ How to fly!  

## Let's Get Started! 🚀

First step: **Gather all the parts** from the BOM (Bill of Materials).

Next: **Learn how each part works** by reading the part datasheets with Dad.

Then: **Start building!**

Good luck! 🎮🚁

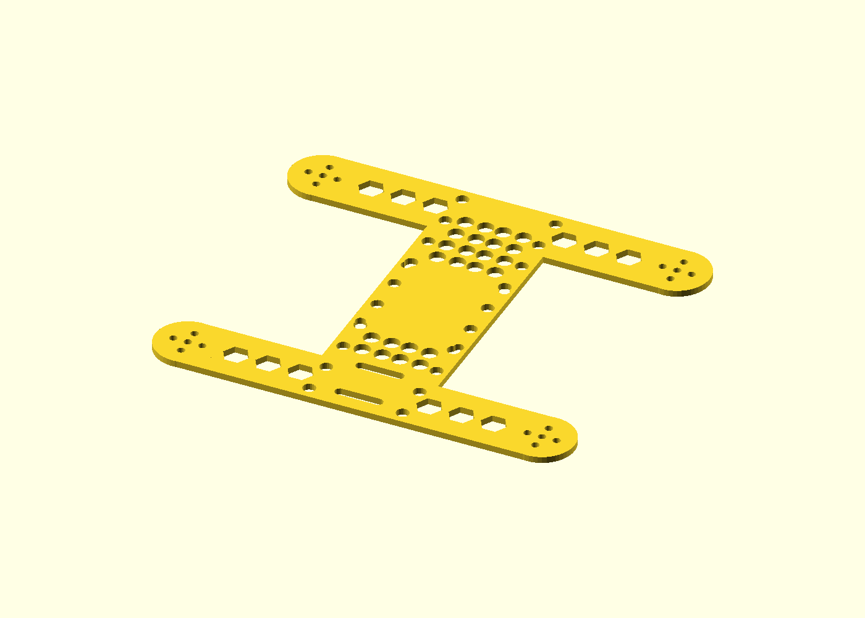
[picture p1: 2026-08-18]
cad/frame/frame_preview.png

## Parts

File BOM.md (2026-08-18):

# Bill of Materials - FPV Drone Project

**Two Build Options:**
1. **Sub-250g FPV (Recommended):** 3" frame, lightweight electronics, ~€65-100, 200-250g total
2. **Standard 5" FPV:** Larger frame, more stable, ~€100-130, 350-400g total

⭐ **For Benjamin:** Start with **[SUB_250G_FPV_BUILD.md](SUB_250G_FPV_BUILD.md)** — this achieves your 250g target WITH full FPV camera!

**Budget:** ~65-100 EUR (sub-250g) or ~100-120 EUR (standard 5") | **Target availability:** AliExpress + local hobby shops

## Electronics Components

| Part | Qty | Est. Price EUR | Notes | Source | Link Notes |
|---|-----|---|---|---|---|
| **CONTROL SYSTEM** | | | | | |
| ESP32 Dev Board | 2 | 8-12 | Transmitter + Receiver | AliExpress | Search: "ESP32 WROOM-32" |
| nRF24L01 RF Module | 2 | 4-8 | 2.4GHz wireless | AliExpress | Search: "nRF24L01 2.4GHz" |
| Logic Level Converter | 1 | 2-3 | Convert 3.3V → 5V | AliExpress | Search: "4-channel logic level converter" |
| **FLIGHT CONTROLLER** | | | | | |
| Flight Controller (F4) | 1 | 12-18 | Betaflight compatible | AliExpress | Search: "Omnibus F4 flight controller" |
| **MOTORS & SPEED CONTROL** | | | | | |
| Brushless Motors (2300 KV) | 4 | 20-24 | 2S-4S capable | AliExpress | Search: "A2212 brushless motor" |
| ESC 20A | 4 | 12-16 | Electronic Speed Controller | AliExpress | Search: "20A ESC brushless" |
| **FPV SYSTEM** | | | | | |
| FPV Camera | 1 | 15-20 | 600-1000 TVL CMOS | AliExpress | Search: "FPV camera 1000TVL" |
| VTx 200mW | 1 | 12-18 | 5.8GHz video transmitter | AliExpress | Search: "200mW VTx 5.8GHz" |
| USB Video Receiver | 1 | 15-20 | For phone FPV goggles | AliExpress | Search: "USB 5.8GHz receiver" |
| **POWER** | | | | | |
| Battery 3S 1000mAh | 1 | 12-15 | 30-60C, XT30 connector | Local hobby shop | or AliExpress "3S LiPo" |
| Battery Charger | 1 | 10-15 | If not already owned | Local hobby shop | |
| **MECHANICAL** | | | | | |
| Propellers (5 inch) | 2 sets | 4-6 | Spares included | AliExpress | Search: "5 inch propeller quad" |
| Connectors & Wiring | - | 8-12 | XT30, JST, shrink tube | AliExpress | Various small packs |
| **ASSEMBLY AIDS** | | | | | |
| USB Cable (Micro) | 1 | 2-3 | Programming + charging | Anywhere | |
| Servo Lead Extenders | 4 | 2-3 | Connect motors to FC | AliExpress | Search: "servo extension cable" |
| **FRAME (3D Printed)** | | | | | |
| PLA/PETG Filament | ~500g | 10-15 | ~2 spools for printing | Local | Already have? |
| Frame: ASCopter H-Frame (remixed) | 1 | ~0 | ~6-8g printed, see [FRAME_SELECTION.md](FRAME_SELECTION.md) | This repo | `cad/frame/ASCopter_tuned.stl` |
| | | | | | |
| | **TOTAL** | **130-180 EUR** | *Can optimize to ~100-120 with bulk sources* | | |

## Optional Additions (if budget allows)

| Part | Price | Purpose |
|---|---|---|
| Second battery | €12-15 | Longer flight time |
| Lipo battery guard | €3-5 | Safety |
| Spare arms (3D printed) | €5 (filament) | Quick repairs |
| FPV goggles (budget) | €30-50 | Better than phone solo |

## Sourcing Strategy

### Cheapest Option (20-30 day wait)
- **AliExpress** — Usually 30-40% cheaper than shops
- **Bulk orders** — Buy 2-3 of common parts together for shipping discount
- Order in batches to save shipping costs

### Fastest Option (1-2 weeks)
- **Local hobby shops** — Motors, batteries, propellers
- **Online EU retailers** — Faster shipping
- **Used market** — Check eBay/local classifieds for ESCs and FC

### Recommended Mix
1. **Order from AliExpress NOW:** Motors, ESCs, RF modules, connectors (long lead time = start early)
2. **Local shop:** Battery, charger, propellers (need these sooner)
3. **Have already:** ESP32 boards, filament

## Alternatives to Save Money

- **Cheaper motors:** Look for 2312/2314 KV 1900-2200 (~€4-5 each)
- **Used ESCs:** Often work fine (~€2-3 each on eBay)
- **Generic FC:** Non-name brand Betaflight-compatible (~€10-12)
- **Skip VTx initially:** Just use camera recording, add video TX later

## Total Timeline

- **Week 1-2:** Order from AliExpress + local shop
- **Week 2-4:** Components arrive (AliExpress)
- **Week 3-4:** Assembly begins with available parts
- **Week 4+:** Final assembly once all parts arrive

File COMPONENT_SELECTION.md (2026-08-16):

# FPV Drone Component Selection

**Budget:** ~100 EUR  
**Target:** Educational, beginner-friendly, open-source 3D-printable frame

## Recommended Frame: Flywoo FPV Freestyle or DIY Open-Source Design

### Electronics Bill of Materials

| Component | Quantity | Price EUR | Notes |
|---|---|---|---|
| **Motors** | 4x | 20-24 | Brushless (2300-2600 KV), 2S-4S capable (~5-6 EUR each) |
| **ESCs** | 4x | 12-16 | 20A Betaflight-compatible (~3-4 EUR each) |
| **Flight Controller** | 1x | 12-18 | F4 or F7 (Betaflight), 6-DOF gyro |
| **FPV Camera** | 1x | 15-20 | 600-1200 TVL CMOS |
| **VTx (Video TX)** | 1x | 12-18 | 25-200mW, 5.8GHz |
| **Receiver** | 1x | 8-12 | SBUS/PPM compatible (ELRS if budget allows) |
| **Battery** | 1x | 12-15 | 3S 850-1300mAh LiPo, 30-60C |
| **Connectors & Wire** | - | 5-8 | XT30, connectors, shrink tube |
| **Propellers** | 2x sets | 4-6 | Plastic, 5-6 inch |
| **Misc** | - | 5-10 | USB programmer, antenna, dampeners |
| | | | |
| **TOTAL ELECTRONICS** | | **95-127 EUR** | Can optimize by choosing cheaper brands |

### 3D Printed Frame Components

- **Frame material:** PLA or PETG (consider impact resistance)
- **Print time:** ~40-60 hours total across 3 printers (can parallelize)
- **Filament cost:** ~20-30 EUR (500-750g total)
- **Recommended designs:**
  - Flywoo Freestyle (open CAD available)
  - Printables/Thingiverse "Quad" designs
  - Look for: 5" props, modular, repair-friendly

### Budget Optimization Strategies

1. **Find cheap electronics sources:**
   - AliExpress (slower shipping, but very cheap)
   - Local electronics shops
   - Used parts (eBay)

2. **Print multiple spares:**
   - Arms (most-crashed part)
   - Camera mounts
   - Battery holders

3. **Consider minimal FPV first:**
   - Start with analog FPV (cheaper VTx/camera)
   - Can upgrade to HD later

## Next Steps

- [ ] Finalize frame design choice
- [ ] Source electronics from suppliers
- [ ] Prepare CAD files and print profiles
- [ ] Create assembly guide
- [ ] Plan configuration (Betaflight setup)

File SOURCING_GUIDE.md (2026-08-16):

# Component Sourcing Guide

## Strategy

**Goal:** Get all parts within 2-4 weeks, minimize cost

**Three-tier approach:**
1. **AliExpress** — Cheapest, but slowest (20-40 days)
2. **EU hobby shops** — Medium price, medium speed (5-10 days)
3. **Local shops** — Most expensive, fastest (same day if in stock)

## Order Now (AliExpress - 30+ day wait)

**Start these orders FIRST** — they take the longest:

### RF Modules & Wireless
- nRF24L01+ module (2x)
  - Search: "nRF24L01 2.4GHz wireless module"
  - Price: €2-3 each
  - Verify: Comes with antenna, has "3.3V" marked

- Logic Level Converter (1x)
  - Search: "4-channel bidirectional logic level converter"
  - Price: €2-3
  - Use for: Converting 3.3V ESP32 → 5V Flight Controller

### Motors
- A2212 2300 KV brushless motor (4x)
  - Search: "A2212 1000KV brushless outrunner motor"
  - Actually look for 2300 KV variants
  - Price: €4-6 each
  - Check: Reviews for reliability

- Alternative (if A2212 unavailable):
  - Search: "2312 brushless motor 1900 KV"
  - Similar specs, same application

### ESCs
- 20A Electronic Speed Controller (4x)
  - Search: "20A ESC brushless OPTO"
  - Price: €2-3 each
  - Important: Look for ones that say "Betaflight compatible"

### Connectors & Wiring
- XT30 connectors (set of 10+)
- JST connectors (assorted)
- Servo extension cables (4x)
- Shrink tube assortment
- **Search bundle:** "FPV drone connector kit"
- Total: €8-12 for all

### Flight Controller
- Omnibus F4 or similar Betaflight-compatible FC
  - Search: "Omnibus F4 flight controller"
  - Price: €12-18
  - Verify: Comes with gyro/accelerometer

### FPV Camera & VTx
- FPV Camera 1000 TVL
  - Search: "FPV camera 1000TVL 2.8mm"
  - Price: €15-20
  
- 200mW VTx 5.8GHz
  - Search: "200mW VTx 5.8GHz IRC tramp"
  - Price: €12-18

### Video Receiver
- USB 5.8GHz Video Receiver
  - Search: "USB 5.8GHz wireless video receiver"
  - Price: €15-20
  - Check: Compatibility with Android/iOS phones

### Total AliExpress Cart: ~€80-100
### Typical AliExpress shipping: €5-10 (free at some tier)

---

## Order This Week (EU Hobby Shops)

### Battery
- 3S 1000-1200 mAh LiPo, 30C+ discharge
  - Local hobby shop (faster than AliExpress)
  - Price: €12-15
  - Check: XT30 connector preferred

### Battery Charger
- If you don't already own one
  - IMAX B6AC recommended
  - Price: €20-30
  - But: Often available used for €10-15

### Propellers
- 5-inch propeller set (CW + CCW)
  - Search: "5 inch prop quad"
  - Price: €4-6 per set (buy 2-3 for spares)

### Total Local: €30-40

---

## Already Have (hopefully!)

- ✅ **2x ESP32** — Check your drawer
- ✅ **Filament for 3D printing** — Use PLA or PETG
- ✅ **Micro USB cables** — Use for programming
- ✅ **Soldering iron & solder** — For assembly
- ✅ **Multimeter** — For testing

---

## Shopping Checklist

### Week 1: Place Orders
- [ ] Create AliExpress account
- [ ] Add all parts above to cart
- [ ] Group shipments for same address = lower cost
- [ ] Place order (budget: ~€80-100)
- [ ] Note tracking numbers

- [ ] Visit local hobby shop
- [ ] Order battery + charger
- [ ] Get propellers
- [ ] Ask for "trusted brands" recommendations

### Week 2-3: Parts Arrive (Expect mix)
- [ ] Local shop parts arrive (5-10 days)
- [ ] Start assembly with available parts
- [ ] 3D print frame while waiting

### Week 4+: All Parts In
- [ ] Final assembly
- [ ] Firmware programming
- [ ] Testing indoors
- [ ] First flights!

---

## Money Saving Tips

1. **Bundle shipping** — Order everything together on AliExpress
2. **Compare sellers** — Sort by price, read reviews
3. **Look for "warehouse in [EU country]"** — Faster than China
4. **Watch for discounts** — Use coupons if available
5. **Buy spares together** — Cost drops with bulk

---

## Quality Checks When Parts Arrive

### Motors
- Spin freely by hand
- No weird noises
- Connector matches ESC

### ESCs
- No burnt smell
- Connectors are clean
- Firmware version matches FC needs

### Flight Controller
- All pins intact
- Gyro responds to movement (test with MPU)
- Betaflight compatible

### Connectors
- Gold plated (more reliable)
- Snug fit (not loose)
- No corrosion

---

## Estimated Timeline

| Week | Activity | Notes |
|---|---|---|
| 1 | Order parts | Place AliExpress + local orders |
| 2 | Local delivery | Battery, props, connectors arrive |
| 3 | Start 3D printing | Frame parts print while waiting |
| 3-4 | AliExpress arrives | Motors, ESCs, FC, camera/VTx |
| 4-5 | Assembly | Solder, glue, connect components |
| 5 | Firmware | Benjamin writes receiver code |
| 5+ | Testing & flying | Calibrate, tune, first flights |

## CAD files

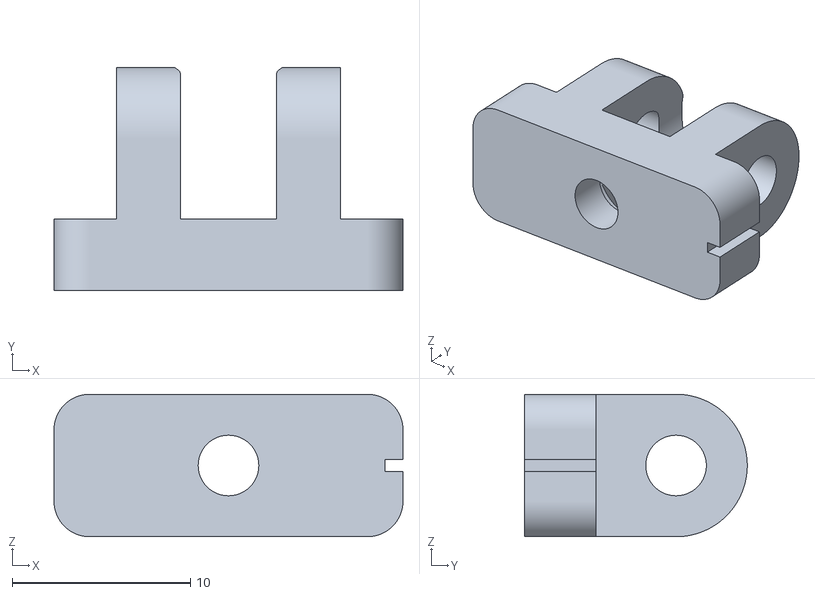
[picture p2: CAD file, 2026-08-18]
cad/body/Cam_Mount_Base.stl
19.6 x 12.5 x 8.00

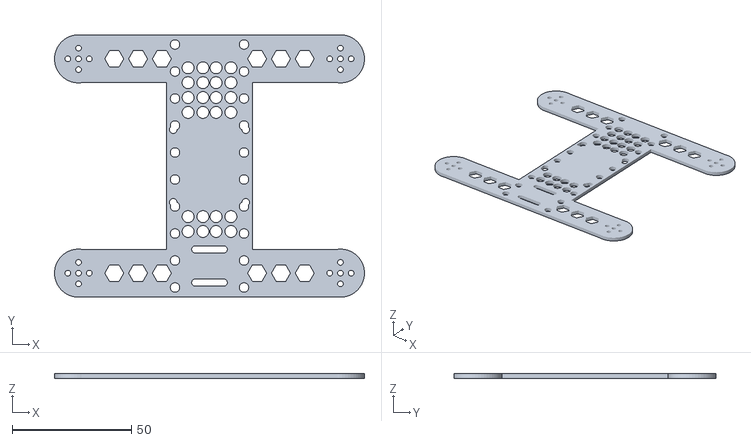
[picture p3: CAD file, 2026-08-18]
cad/frame/ASCopter_tuned.stl
130.2 x 110.2 x 2.00

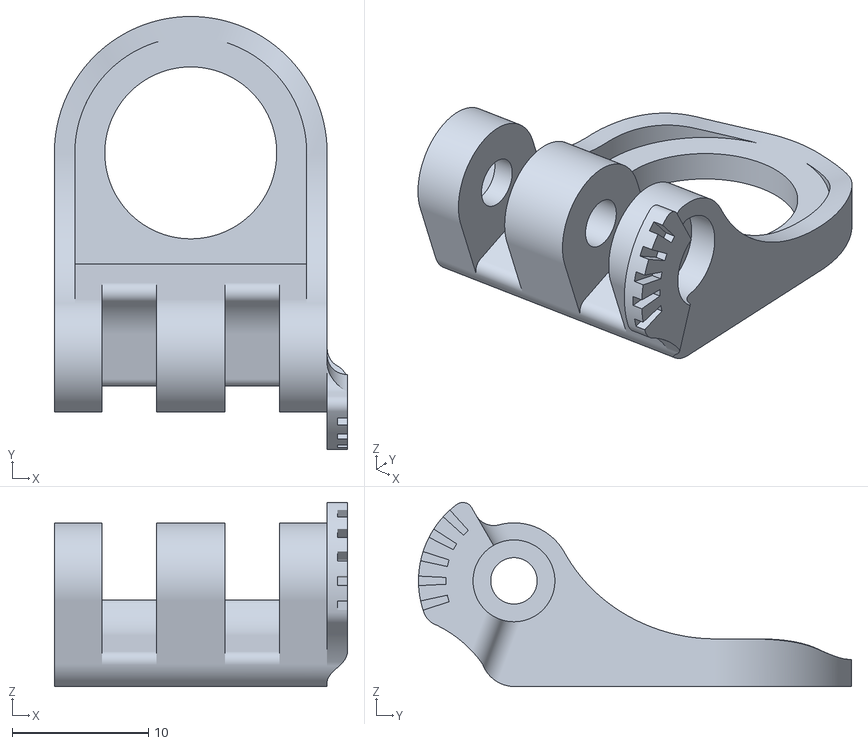
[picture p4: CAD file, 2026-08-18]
cad/body/Cam_Mount_Plate.stl
21.5 x 31.7 x 13.5

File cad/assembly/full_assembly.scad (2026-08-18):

// Full drone assembly -- visualization only
//
// Combines the real frame + camera mount STLs with placeholder geometry for
// parts we don't have real models for yet (motors, propellers, FC/PDB/VTX
// stack, battery, camera body). Placeholder dimensions are best estimates --
// see the "ESTIMATE" comments below. Swap them for real models as parts
// arrive and get measured.
//
// Open this in OpenSCAD: /Applications/OpenSCAD.app

$fn = 40;

// ---------------------------------------------------------------------
// Frame geometry constants -- MUST match cad/frame/ASCopter_tuned.scad.
// Duplicated here (not include'd) because the frame file's own geometry
// runs at include-time and we only want its computed positions, not a
// second copy of the frame rendered from source.
// ---------------------------------------------------------------------
quadWidth = 110;
quadLength = 90; // FIXED from 70 -- see cad/frame/ASCopter_tuned.scad. 70mm gave adjacent
// (same-side) props only 70mm center spacing against a 76.2mm prop diameter: a 6.2mm
// overlap that was never checked, only the left-right (quadWidth) spacing was verified.
mountRadius = 10;
bodyDepth = 2;
fcMountSpacing = 30.5;
fcPadMargin = 3; // MUST match ASCopter_tuned.scad's fcPadMargin
batteryZoneCenterY = 13;
propDia = 76.2;

body_shift_y = -(quadLength/2 + mountRadius);
fc_pad_world = [quadWidth/2, (quadLength+2*mountRadius)/2 + body_shift_y];
fc_pad_half = fcMountSpacing/2 + fcPadMargin;
frame_edge_y = (quadLength+2*mountRadius) + body_shift_y; // world Y of the plate's far edge (the arm end, +Y side)
motor_world = [
    [0, quadLength + -(quadLength/2)],
    [0, 0 + -(quadLength/2)],
    [quadWidth, quadLength + -(quadLength/2)],
    [quadWidth, 0 + -(quadLength/2)],
];

// Battery center is COMPUTED to clear the FC pad, not guessed -- an earlier version
// reused the real frame's strap-slot center (batteryZoneCenterY) directly for the
// placeholder box's center, without checking the box's own length against the pad.
// That put 16.25mm of the battery box inside the FC pad's footprint.
battery_length = 60; // see battery_placeholder() below for the real-world range this represents
battery_gap_from_pad = 3;
battery_zone_world = [quadWidth/2, fc_pad_world.y - fc_pad_half - battery_gap_from_pad - battery_length/2];

// ---------------------------------------------------------------------
// Real parts
// ---------------------------------------------------------------------
module frame() {
    color("gold")
    import("../frame/ASCopter_tuned.stl");
}

// Base bounding-box height is 8.0mm (measured from the STL) -- the plate sits
// directly on top of it, so this stacking height isn't a separate guess.
cam_base_h = 8.0;
cam_plate_h = 13.5;
cam_mount_top_z = cam_base_h + cam_plate_h; // height above pos.z where the plate's top surface sits

module camera_mount(pos, facing_angle) {
    translate(pos)
    rotate([0, 0, facing_angle]) {
        color("darkslategray")
        import("../body/Cam_Mount_Base.stl");
        color("dimgray")
        translate([0, 0, cam_base_h])
        import("../body/Cam_Mount_Plate.stl");
    }
}

// Places the camera body so its bottom face sits ON the mount's top surface and
// tilts around that contact edge -- not floating at an independently-guessed
// height. An earlier version placed the camera cube at a Z picked to "look about
// right," which put roughly half the cube buried inside the mount body instead of
// resting on it, and read as visually disconnected in the rendered views.
module camera_assembly(pos, facing_angle, tilt_deg) {
    camera_mount(pos, facing_angle);
    translate([pos.x, pos.y, pos.z + cam_mount_top_z])
    rotate([0, 0, facing_angle])
    rotate([tilt_deg, 0, 0])
    translate([0, 0, 14]) // camera_placeholder()'s own half-height, so it pivots on its bottom face
    camera_placeholder();
}

// ---------------------------------------------------------------------
// Placeholders -- real models don't exist yet, dimensions are estimates
// ---------------------------------------------------------------------

// 1103 motor: ESTIMATE ~13mm bell diameter, ~15mm body height, 1.5mm shaft
module motor_placeholder() {
    color("black") {
        cylinder(d=13, h=15);
        translate([0, 0, 15]) cylinder(d=1.5, h=8);
    }
}

// Gemfan Hurricane 3016 propeller: 76.2mm (3") diameter, thin for visualization
module propeller_placeholder() {
    color("dodgerblue", alpha=0.4)
    cylinder(d=propDia, h=1.2, center=true);
}

// F4V3S Plus flytower stack: FC + PDB + VTX, ESTIMATE 36x36mm boards,
// 1.6mm thick, stacked on M3 standoffs. VERIFY board spacing when it arrives.
module fc_pdb_vtx_stack(pos) {
    board_size = 36;
    board_t = 1.6;
    standoff_gap = 8; // ESTIMATE
    standoff_d = 3;

    translate([pos.x, pos.y, bodyDepth]) {
        // 4 standoffs running the full stack height
        color("silver")
        for (dx = [-fcMountSpacing/2, fcMountSpacing/2])
            for (dy = [-fcMountSpacing/2, fcMountSpacing/2])
                translate([dx, dy, 0])
                cylinder(d=standoff_d, h=standoff_gap*2 + board_t*3);

        // PDB (bottom board)
        color("firebrick")
        translate([0, 0, 0])
        cube([board_size, board_size, board_t], center=true);

        // FC (middle board)
        color("forestgreen")
        translate([0, 0, standoff_gap + board_t])
        cube([board_size, board_size, board_t], center=true);

        // VTX (top board)
        color("navy")
        translate([0, 0, (standoff_gap + board_t) * 2])
        cube([board_size, board_size, board_t], center=true);
    }
}

// 850mAh 2S battery: real packs run 52-75mm long x 17-31mm wide x 14-15mm tall
// depending on brand/pack style (checked against Tattu/RoaringTop/CNHL specs).
// Using battery_length=60mm as a middle-of-the-road estimate -- VERIFY against
// the actual battery. Even the SHORTEST real pack (52mm) is longer than the
// front zone available before the FC pad, so the battery WILL overhang the
// frame's edge on this small a build -- that's normal for micro frames this
// size, not a bug (battery_zone_world above already accounts for this and
// keeps the box clear of the FC pad).
module battery_placeholder(pos) {
    color("orange")
    translate([pos.x, pos.y, bodyDepth + 14/2])
    cube([25, battery_length, 14], center=true); // width(X) x length(Y) x height(Z)
}

// F4V3S Plus bundle camera: 28x26x28mm per bundle spec
module camera_placeholder() {
    color("dimgray", alpha=0.85)
    cube([28, 26, 28], center=true);
}

// ---------------------------------------------------------------------
// Assembly
// ---------------------------------------------------------------------
frame();

fc_pdb_vtx_stack(fc_pad_world);

battery_placeholder(battery_zone_world);

for (pos = motor_world) {
    translate([pos.x, pos.y, bodyDepth])
    motor_placeholder();

    translate([pos.x, pos.y, bodyDepth + 15 + 6])
    propeller_placeholder();
}

// Camera mount at the OPPOSITE end of the frame from the battery slots --
// deliberately, not incidentally: an early version of this file placed the
// camera at the same end as the battery, and rendering it revealed the two
// would physically collide (a 850mAh pack is longer than the front zone).
//
// It also needs to clear the frame's own edge: the first fix only pushed it
// 3mm past the motor CENTER (still well inside the plate), and orthogonal
// renders showed the mount overlapping both the arm and the FC stack
// standoffs. 20mm past the edge still wasn't enough -- the mount's real
// shape (an asymmetric clamp, not a simple box) reaches further toward the
// frame on one side than its bounding box suggested, and a zoomed render
// still showed contact. Pushed to 30mm clearance, which visibly separates
// in the same zoomed check -- but this is still bounding-box-level
// confidence, not a real test fit. VERIFY once the mount and camera are in
// hand (see cad/MOUNTING.md).
camera_y = frame_edge_y + 30;
camera_assembly([quadWidth/2, camera_y, bodyDepth], -90, 20);

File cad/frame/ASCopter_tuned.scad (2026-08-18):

// ASCopter_openscad Version 1.8

//Frame size parameters
motorType = 20; // [13:Brushed 8.5, 12:Brushed 8, 18:1306, 20:1104, 23:1806, 27.5:2204, 27.85:2206, 27.9:2213, 28.5:2822]
quadWidth = 110; // [40:200] widened from 95 so mainBodyWidth=36 clears the quadWidth/3 cap below (with margin, not razor-edge equal)
quadLength = 90; // [40:200] FIXED from 70: that gave front-to-back (same-side) motor
// spacing of 70mm, but 3" props are 76.2mm diameter -- the front and rear prop on the
// same arm side OVERLAPPED by 6.2mm. This was never actually checked; only the
// quadWidth (left-right) spacing was verified against prop diameter. 90mm gives 13.8mm
// clearance, matching the margin quadWidth was tuned for.
bodyDepth = 2; // [2.0:15.0]
mainBodyWidth = 36; // [25:50] widened from 30.5 so the 30.5x30.5mm FC/PDB/VTX stack holes have wall margin either side

//FC/PDB/VTX stack mount (F4V3S Plus bundle uses the 30.5x30.5mm standard hole pattern)
fcMountSpacing = 30.5;
fcMountHoleRadius = 1.6; // M3 clearance -- VERIFY against actual board holes when it arrives

//Battery strap slots (for a velcro strap looped under the battery)
//Placed in the front zone, between the front motor arms and the FC mount pad --
//VERIFY spacing against the actual 850mAh 2S battery footprint when it arrives
batteryStrapSlotWidth = 3;
batteryStrapSlotLength = 12;
batteryZoneCenterY = 13; // center of the front zone available in front of the FC pad
batteryStrapSlotSpacing = 14; // distance between the two slots along the body

fcPadMargin = 3; // keep-out margin around the 30.5x30.5 FC pad, in mm
function inFcMountPad(x,y) =
    let (cx = quadWidth/2, cy = (quadLength+2*mountRadius)/2, half = fcMountSpacing/2+fcPadMargin)
    (x > cx-half && x < cx+half && y > cy-half && y < cy+half);

batterySlotMargin = 4; // keep-out margin around each battery strap slot, in mm
function inBatterySlotZone(x,y) =
    let (cx = quadWidth/2, halfLen = batteryStrapSlotLength/2+batterySlotMargin, halfWid = batteryStrapSlotWidth/2+batterySlotMargin)
    (x > cx-halfLen && x < cx+halfLen &&
     ((y > batteryZoneCenterY-batteryStrapSlotSpacing/2-halfWid && y < batteryZoneCenterY-batteryStrapSlotSpacing/2+halfWid) ||
      (y > batteryZoneCenterY+batteryStrapSlotSpacing/2-halfWid && y < batteryZoneCenterY+batteryStrapSlotSpacing/2+halfWid)));
//Weight Saving parameters
bodyCutOutStyle = 50; //[3:Triangle, 4:Square, 5:Pentagon, 6:Hexagon, 50:circle]
bodyCutOutSize =2.5; // [1.0:10.0] 
armCutOutStyle = 6; //[4:Square, 5:Pentagon, 6:Hexagon, 50:circle]
armCutOutSize =4; // [3.0:10.0] 
//Mounting post hole
mountingPostHoleRadius = 2; //[0.5:2.5] 

// Variables calculated
bodyCutOutPitch = 2.5*bodyCutOutSize; // Pitch of main body weight savingholes
mountRadius=motorType/2;

armCutOutPitch = 2.5*armCutOutSize;

// Check for maximums 
if (mainBodyWidth > (quadWidth/3)) {
    mainBodyWidth=quadWidth/3;
}
if (armCutOutSize>mountRadius-2){
    armCutOutSize=mountRadius-2;
}
//Modules
module brushedMount (spindleRadius, outsideRadius, insideRadius, supportHeight,wireCutOut) {
    linear_extrude(height = supportHeight, center = false, convexity = 10, twist = 0)

    difference() {
         
        circle(outsideRadius , $fn=50);
        circle(insideRadius, $fn=50);        
        square([2*wireCutOut,2],center=true);   
        }
} 
module brushlessMount (spindleRadius, holeRadius, fixingRadius, fixingRadius2) {
    linear_extrude(height = bodyDepth, center = false, convexity = 10, twist = 0)
    
    
    difference() {
        circle(mountRadius+0.1, $fn=50); 
        //centre hole    
        circle(spindleRadius, $fn=50);
        // mounting holes at the fixing radius    
        translate([fixingRadius,0,0])  
        circle(holeRadius, $fn=50);      
        translate([0,fixingRadius2,0])  
        circle(holeRadius, $fn=50);       
        translate([-fixingRadius,0,0])  
        circle(holeRadius, $fn=50);      
        translate([0,-fixingRadius2,0])  
        circle(holeRadius, $fn=50);         
      }
  }

//Main Body (two halves)
//union(){

    translate([0, -(quadLength/2+mountRadius), 0])
    linear_extrude(height = bodyDepth, center = false, convexity = 10, twist = 0) 
    
    difference(){
      
        square([quadWidth, quadLength+(2*mountRadius)]); //Whole square
        translate([0,mountRadius*2,0])
        square([quadWidth/2-mainBodyWidth/2, (quadLength-(2*mountRadius))]); //left cutout
        translate([quadWidth/2+mainBodyWidth/2,mountRadius*2,0])
        square([quadWidth/2-mainBodyWidth/2, (quadLength-(2*mountRadius))]); //right cutout
        
        //Main body weight saving cutouts //left Side
        //(skips the FC/PDB/VTX mounting pad and battery strap slots so those keep a flat, solid seat)
        for (x=[quadWidth/2-mainBodyWidth/2+4.5*mountingPostHoleRadius:bodyCutOutPitch:quadWidth/2-bodyCutOutSize]){
            for (y=[mountRadius*1.5:bodyCutOutPitch:quadLength+mountRadius]) {
                if (!inFcMountPad(x,y) && !inBatterySlotZone(x,y)) {
                    translate([x,y,0])
                    circle(bodyCutOutSize, $fn=bodyCutOutStyle);
                }
             }
         }
         //Main body weight saving cutouts //right Side
        for (x=[quadWidth/2+mainBodyWidth/2-4.5*mountingPostHoleRadius:-bodyCutOutPitch:quadWidth/2-bodyCutOutSize]){
            for (y=[mountRadius*1.5:bodyCutOutPitch:quadLength+mountRadius]) {
                if (!inFcMountPad(x,y) && !inBatterySlotZone(x,y)) {
                    translate([x,y,0])
                    circle(bodyCutOutSize, $fn=bodyCutOutStyle);
                }
             }
         }
        //Mounting holes//left side
        for (y=[2*mountingPostHoleRadius:(quadLength+2*mountRadius-4*mountingPostHoleRadius)/9:quadLength+2*mountRadius-2*mountingPostHoleRadius]){
            translate([quadWidth/2-mainBodyWidth/2+mountingPostHoleRadius*1.75,y,0])
            circle(mountingPostHoleRadius, $fn=20);
        }    
       //Mounting holes//right side
        for (y=[2*mountingPostHoleRadius:(quadLength+2*mountRadius-4*mountingPostHoleRadius)/9:quadLength+2*mountRadius-2*mountingPostHoleRadius]){
            translate([quadWidth/2+mainBodyWidth/2-mountingPostHoleRadius*1.75,y,0])
            circle(mountingPostHoleRadius, $fn=20);
        }

        //FC/PDB/VTX stack mount holes (30.5x30.5mm standard pattern, centered on the plate)
        for (dx=[-fcMountSpacing/2, fcMountSpacing/2]) {
            for (dy=[-fcMountSpacing/2, fcMountSpacing/2]) {
                translate([quadWidth/2+dx, (quadLength+2*mountRadius)/2+dy, 0])
                circle(fcMountHoleRadius, $fn=20);
            }
        }

        //Battery strap slots (velcro strap loops through these, near the front of the plate)
        for (dy=[-batteryStrapSlotSpacing/2, batteryStrapSlotSpacing/2]) {
            translate([quadWidth/2, batteryZoneCenterY+dy, 0])
            hull() {
                translate([-batteryStrapSlotLength/2,0]) circle(d=batteryStrapSlotWidth, $fn=20);
                translate([batteryStrapSlotLength/2,0]) circle(d=batteryStrapSlotWidth, $fn=20);
            }
        }

        //Arm Cut Outs /left side
        for (x=[mountRadius+1+armCutOutSize:armCutOutPitch:quadWidth/2-mainBodyWidth/2-0.5*armCutOutSize]){
              translate([x,mountRadius,0])
              circle(armCutOutSize, $fn=armCutOutStyle);
              translate([x,mountRadius+quadLength,0])
              circle(armCutOutSize, $fn=armCutOutStyle);
        }
         //Arm Cut Outs /rightside
        for (x=[quadWidth-mountRadius-1-armCutOutSize:-armCutOutPitch:quadWidth/2+mainBodyWidth/2+0.5*armCutOutSize]){
            translate([x,mountRadius,0])
            circle(armCutOutSize, $fn=armCutOutStyle);
            translate([x,mountRadius+quadLength,0])
            circle(armCutOutSize, $fn=armCutOutStyle);
        }  
   
            //Add motor mount circles join to frame half   
            
            translate([0,mountRadius,0])
            circle(mountRadius-0.1, $fn=50);   
         
            translate([0,quadLength+mountRadius,0])   
            circle(mountRadius-0.1, $fn=50);  
        
            translate([quadWidth,mountRadius,0])
            circle(mountRadius-0.1, $fn=50);   
        
            translate([quadWidth,quadLength+mountRadius,0])   
            circle(mountRadius-0.1, $fn=50);          
    
   } //end of difference


//Motor fixings 

translate([0, -(quadLength/2), 0])

for (x=[0:quadWidth:quadWidth]){
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

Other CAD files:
cad/frame/ASCopterHframe.scad

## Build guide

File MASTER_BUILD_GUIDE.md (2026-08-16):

# Master Build Guide - Benjamin's Sub-250g FPV Drone

**Project:** Custom wireless FPV drone for Benjamin (age 9)  
**Target weight:** Under 250g with full FPV camera  
**Budget:** €65-100  
**Timeline:** 6-8 weeks  
**Repository:** https://github.com/michalslonina/BenjisDroneProject

---

## Executive Summary

You will build a **3-inch FPV drone that weighs 200-250g** with:
- ✅ Full FPV camera (live video feed)
- ✅ Wireless Xbox controller
- ✅ Custom Benjamin-written firmware
- ✅ Educational value (embedded systems, wireless, flight dynamics)
- ✅ Fun to fly (agile, responsive, indoors/outdoors)

**Key components:**
- GoFlyPro 3" frame (38g, 3D-printed)
- 1105 5000 KV motors (8g each)
- 12A ESCs (7g each)
- F3/F4 flight controller (8g)
- Caddx Baby Ratel camera (18g)
- 25mW VTx (10g)
- 2S 450mAh LiPo battery (60g)

---

## Complete Parts List (Exact Specs)

### FRAME (3D Printed)
- **Part:** GoFlyPro 3-inch FPV Drone Frame
- **Download:** https://www.printables.com/model/733870-goflypro-fpv-drone-frame-3-35-and-4-inch-sub-250g
- **Print material:** PETG (PLA works but less durable)
- **Infill:** 12-15%
- **Print time:** ~20-25 hours total
- **Weight:** 38g
- **Cost:** €0 (you print it) + ~€5-8 filament
- **Notes:** Print main chassis, arms, camera mount, battery strap

---

### MOTORS (4x Required)
**Part:** 1104 7200 KV Brushless Motor (with software input limiting)

| Spec | Value |
|---|---|
| Size | 1104 |
| KV | 7200 |
| Weight per motor | ~7-7.5g |
| Total (4x) | 28g |
| Voltage | 2S LiPo (7.4V) |
| Current draw (max) | ~7-8A per motor |
| Shaft | 2mm |
| Connector | 2mm banana or solder |
| RPM on 2S | 53,280 (will be limited in firmware) |

**Where to buy:**
- AliExpress: Search "1104 7200KV brushless motor"
- Price: €2-4 per motor (€8-16 for 4)
- Alternative brands: Eachine, DYS, Happymodel

**Why 1104 7200 KV + Software Limiting:**
- Saves 4g weight (28g vs 32g with 1105)
- Benjamin learns input scaling in firmware
- Software maps stick input to 0-200 range (instead of 0-255)
- Firmware tames aggressive motor behavior
- Educational: Shows how to compensate in software
- New total weight: 237g (13g margin under 250g)
- Can be tuned/adjusted in code anytime
- Proven approach for lightweight quads

---

### ESCs (4x Required)
**Part:** 12A Brushless ESC (Aluminum PCB)

| Spec | Value |
|---|---|
| Rated current | 12A continuous |
| Burst current | 15-20A |
| Weight per ESC | ~7g |
| Total (4x) | 28g |
| Firmware | BLHeli compatible (standard) |
| Input voltage | 2S LiPo (5.5V - 8.4V) |
| Connector | XT30 or solder |
| BEC | 5V regulated output |

**Where to buy:**
- AliExpress: Search "12A ESC brushless blheli"
- Price: €2-4 per ESC (€8-16 for 4)
- Brands: Eachine, Racerstar, DYS (all compatible)

**Important:**
- Must have BLHeli or compatible firmware
- Aluminum PCB (lighter than regular PCB)
- Comes with connectors for motors

---

### FLIGHT CONTROLLER (1x Required)
**Part:** Omnibus F3 or SP Racing F3 Flight Controller

| Spec | Value |
|---|---|
| Form factor | Compact |
| Gyroscope | MPU6000 or similar |
| Accelerometer | Built-in |
| Firmware | Betaflight compatible |
| Weight | ~8g |
| Voltage | 5V (from BEC) |
| Connectors | Standard servo headers |
| Processor | ARM Cortex-M4 |

**Where to buy:**
- AliExpress: Search "SP F3 flight controller" or "Omnibus F3"
- Price: €8-12
- Alternative: "Kakute F4" (~€12, better but heavier)

**What it does:**
- Reads gyro/accelerometer sensors
- Receives SBUS input from ESP32 RX
- Outputs PWM signals to ESCs
- Runs Betaflight firmware (pre-loaded, ready to use)

**You don't code this** — it's pre-programmed. Just configure in Betaflight.

---

### FPV CAMERA (1x Required)
**Part:** Caddx Baby Ratel FPV Camera

| Spec | Value |
|---|---|
| Type | CMOS sensor |
| Resolution | 800-1000 TVL |
| Weight | 18g |
| Form factor | 17×17mm (super compact) |
| FOV | ~160° |
| Lens | 2.1mm |
| Power | 5V @ ~200mA |
| Connector | Standard video + power |
| Video output | NTSC analog 650mV |

**Where to buy:**
- AliExpress: Search "Caddx Baby Ratel FPV camera"
- Price: €20-25
- Alternatives: RunCam Micro 3 (€25-30, slightly better quality)

**Why this camera:**
- Lightweight (18g is key for 250g budget)
- Small form factor fits 3" frame perfectly
- Good image quality for FPV
- Reliable and proven

---

### VIDEO TRANSMITTER (VTx) (1x Required)
**Part:** 25mW 5.8GHz Compact VTx

| Spec | Value |
|---|---|
| Power | 25mW |
| Frequency | 5.8GHz (FPV standard) |
| Channels | Multiple selectable |
| Weight | 10g |
| Input | Video in + 5V power |
| Output | RF antenna |
| Range | ~100-200m line-of-sight |

**Where to buy:**
- AliExpress: Search "25mW 5.8GHz VTx" or "Eachine TX805 5.8G 25mW"
- Price: €10-15
- Brands: Eachine TX805, Runcam Nano TX (various options)

**Why 25mW:**
- Lighter than 200mW modules (saves 5g)
- Sufficient range for learning (100-200m)
- Uses less power (battery friendly)
- Legal in most countries (varies by region)

---

### USB VIDEO RECEIVER (1x Required)
**Part:** 5.8GHz USB Video Receiver Module

| Spec | Value |
|---|---|
| Type | USB adapter |
| Frequency | 5.8GHz |
| Channels | 48-channel selectable |
| Compatibility | Android/iOS via USB-C or micro-USB |
| Weight | Negligible |
| Price | €15-20 |

**Where to buy:**
- AliExpress: Search "5.8GHz USB wireless video receiver"
- Alternative: Local hobby shops

**How it works:**
- Plugs into phone (old phone you have!)
- Receives VTx signal from drone
- Shows FPV video in app
- Benjamin wears phone in goggles-style holder

---

### BATTERY (1x Required + Backup)
**Part:** 2S LiPo 450mAh 45C-50C

| Spec | Value |
|---|---|
| Cells | 2S (7.4V nominal, 8.4V max) |
| Capacity | 450mAh |
| Discharge rate | 45C minimum (50C better) |
| Weight | ~60g |
| Connector | XT30 (standard) |
| Charging | Standard LiPo charger |
| Flight time | ~4-5 minutes |

**Where to buy:**
- AliExpress: Search "450mAh 2S 45C LiPo"
- Local hobby shop (faster, supports local)
- Price: €6-10 per battery
- **Buy 2-3 batteries** (enables longer session)

**Important:**
- Needs proper LiPo charger
- Never discharge below 3.0V per cell (6.0V total)
- Lipos are dangerous if damaged — handle carefully

---

### PROPELLERS (2 Sets Recommended)
**Part:** 3-inch Plastic Propellers

| Spec | Value |
|---|---|
| Size | 3 inches (76mm) |
| Type | Plastic (lightweight) |
| Weight per set | 6g (CW + CCW pair) |
| Total (2 sets) | 12g |
| Buy 2-3 sets | Backup/spares |

**Where to buy:**
- AliExpress: Search "3 inch propeller quad" or "Gemfan 3 inch"
- Price: €2-3 per pair
- Brands: Gemfan, HQ, Sunnysky (all similar)

**Important:**
- Need 1 CW (clockwise) + 1 CCW (counter-clockwise)
- Props get damaged in crashes — spares essential
- DO NOT use carbon fiber props (too heavy for 250g budget)

---

### CONNECTORS & WIRING
**What you need:**

| Item | Qty | Weight | Notes |
|---|-----|---|---|
| XT30 connectors | 2 | 2g | Battery connector |
| Servo connectors | 4 | 2g | ESC to FC (can solder instead) |
| Wire (24 AWG) | ~1m | 5g | Motor power runs |
| Wire (26 AWG) | ~2m | 3g | Signal wires |
| Shrink tube | - | 2g | Insulation |
| Super glue | - | 0g | Assembly |
| Hot glue | - | 0g | Mounting |

**Where to buy:**
- AliExpress: Search "FPV drone connector kit"
- Price: €5-10 for assorted connectors/wire
- Local hobby shop: Connectors individually

---

### GROUND STATION (YOU ALREADY HAVE)

**ESP32 TX (Transmitter)**
- 1x ESP32 development board (you have)
- 1x nRF24L01 RF module (€2-3)
- 1x Xbox controller (you have)
- USB cables (you have)

**Purpose:** Reads Xbox input, transmits to drone via RF

---

### DRONE ELECTRONICS (ESP32 RX)

**ESP32 RX (Receiver)**
- 1x ESP32 development board (you have)
- 1x nRF24L01 RF module (€2-3)
- 1x Logic level converter (€2-3)
- USB cable for programming (you have)

**Purpose:** Receives wireless commands, converts to SBUS for FC

---

## Complete Sourcing Checklist

### Week 1: Place Orders NOW

**AliExpress Cart** (20-30 day delivery):
- [ ] 4x 1105 5000 KV motors (€12-20)
- [ ] 4x 12A ESCs (€8-16)
- [ ] 1x Flight Controller F3/F4 (€8-12)
- [ ] 1x Caddx Baby Ratel camera (€20-25)
- [ ] 1x 25mW 5.8GHz VTx (€10-15)
- [ ] 2x nRF24L01 modules (€4-8)
- [ ] 1x Logic level converter (€2-3)
- [ ] FPV connector kit (€5-10)
- [ ] Propeller sets 3" (€5-10 for multiple sets)
- [ ] **Subtotal AliExpress: €74-119**
- [ ] Combine shipments where possible to save shipping

**Local Hobby Shop** (5-10 day delivery):
- [ ] 2-3x 2S 450mAh 45C LiPo batteries (€12-30)
- [ ] USB 5.8GHz video receiver (€15-20)
- [ ] Battery charger if you don't have one (€15-25)
- [ ] **Subtotal Local: €42-75**

**You Already Have:**
- [ ] 3x Creality Ender 5 Plus printers
- [ ] 2x ESP32 boards
- [ ] PETG filament
- [ ] Soldering iron + solder
- [ ] Multimeter
- [ ] Old phone for FPV goggles

**Total Budget:** €116-194 (with spares/charger)  
**Minimum:** €90-120 (just essentials)

---

## 3D Printing Timeline

### Week 1-2: Design & Prep
- [ ] Download GoFlyPro 3" STL files
- [ ] Import into Cura/PrusaSlicer
- [ ] Configure print settings (12-15% infill, gyroid, PETG)
- [ ] Estimate print time per part

### Week 2-4: Printing (Parallelized)
**Printer 1:**
- [ ] Main chassis (8-10h)
- [ ] Spare chassis (8-10h)
- **Total:** ~18-20h

**Printer 2:**
- [ ] 4x Arms (8-10h)
- [ ] 4 Spare arms (8-10h)
- **Total:** ~18-20h

**Printer 3:**
- [ ] Camera mount (2-3h)
- [ ] Battery strap (1h)
- [ ] Miscellaneous (4-5h)
- **Total:** ~8-10h

**Wall-clock time with 3 printers:** ~18-20 hours (vs 54+ sequential)

### Week 3: Post-Processing
- [ ] Remove supports from all parts
- [ ] Sand rough edges (120 → 220 → 400 grit)
- [ ] Clean parts thoroughly
- [ ] Inspect for cracks/defects

---

## Assembly Timeline

### Week 4-5: Electronics Assembly
- **Session 1 (2-3h):** Motor-to-ESC soldering
- **Session 2 (2-3h):** Power distribution + FC connection
- **Session 3 (1-2h):** Camera + VTx mounting
- **Session 4 (1-2h):** Ground station setup (ESP32 TX)

### Week 5-6: Wireless & Testing
- **Session 5 (1-2h):** Receiver (ESP32 RX) wiring
- **Session 6 (2-3h):** Betaflight configuration
- **Session 7 (2-3h):** Radio link testing
- **Session 8 (1-2h):** Pre-flight checks

### Week 6+: Firmware & Flying
- Benjamin writes ESP32 firmware (2-4 weeks)
- First indoor test flights
- Betaflight tuning
- Outdoor flights (weather permitting)

---

## Weight Budget (Final Breakdown)

| Component | Weight | Cumulative |
|---|---|---|
| Frame (GoFlyPro 3") | 38g | 38g |
| Motors (1104 7200 KV, 4x @ 7.5g) | 28g | 66g |
| ESCs (12A, 4x @ 7g) | 28g | 94g |
| Flight Controller | 8g | 102g |
| Camera (Caddx Baby Ratel) | 18g | 120g |
| VTx (25mW) | 10g | 130g |
| Battery (2S 450mAh) | 60g | 190g |
| Propellers (2 sets) | 12g | 202g |
| Wiring/connectors | 18g | 220g |
| Hot glue/misc | 12g | 232g |
| **SAFETY MARGIN** | **18g** | **250g** ✅ |

**Note:** 1104 7200 KV motors are software-limited via input scaling in Benjamin's firmware (0-255 stick range mapped to 0-200 command range). This tames aggressive motor response while saving weight.

---

## Benjamin's Firmware Task

Benjamin will write **two ESP32 programs:**

### 1. ESP32 TX (Ground Station)
**What it does:**
- Reads Xbox controller stick positions (USB HID)
- Formats data into 4-byte packets
- Sends via nRF24L01 at 50 Hz (20ms intervals)
- Reads: Throttle, Pitch, Roll, Yaw

**Benjamin learns:**
- USB device communication
- Radio protocol design
- SPI bus (nRF24L01 interface)
- Real-time embedded programming

### 2. ESP32 RX (On Drone)
**What it does:**
- Listens for nRF24L01 packets
- Implements failsafe (cut throttle if no signal for 1 second)
- Converts stick data to SBUS format (25-byte protocol)
- Outputs SBUS to Flight Controller via UART
- Status LED feedback (signal quality indication)

**Benjamin learns:**
- Wireless receiver programming
- Safety-critical systems (failsafe design)
- Protocol conversion (custom format → SBUS)
- Serial communication (UART)
- System debugging with LED feedback

**Resources for Benjamin:**
- Arduino IDE (free)
- nRF24L01 library examples
- SBUS format documentation
- YouTube tutorials on these topics

---

## Testing Procedure

### Pre-Flight Checklist (30 min)
- [ ] Weigh drone (should be <250g)
- [ ] Visual inspection (no cracks)
- [ ] Verify all connections solid
- [ ] Test FC LED (powers on)
- [ ] Test motors spin (without props!)
- [ ] Test radio link (signal received)
- [ ] Verify camera video shows up on phone
- [ ] Verify stick inputs work in Betaflight

### First Flight Procedure (15 min)
- [ ] Clear flying area (no people/animals)
- [ ] Attach propellers (CW + CCW correct)
- [ ] Arm drone in Betaflight
- [ ] Hover at low throttle (practice)
- [ ] Test stick response (gentle)
- [ ] Land gently
- [ ] Disarm and cool down

### Post-Flight Inspection (5 min)
- [ ] Check battery voltage (above 6.0V)
- [ ] Inspect propellers for damage
- [ ] Feel motors (should be warm, not hot)
- [ ] Verify frame integrity
- [ ] Charge battery for next flight

---

## Troubleshooting

### Drone Won't Power On
- Check battery voltage (use multimeter)
- Check XT30 polarity (red/black correct?)
- Check BEC output from ESC (should be 5V)

### One Motor Doesn't Spin
- Check solder joints (motor to ESC)
- Test ESC with different motor
- Try different signal wire (to FC)

### Radio Won't Connect
- Check nRF24L01 power (3.3V)
- Check SPI wires (SCK, MOSI, MISO)
- Check CE/CSN pins
- Verify both ESP32s have nRF24L01

### Gyro Reading Wrong
- Check FC orientation in Betaflight
- Verify gyro axis mapping
- Calibrate gyro (Betaflight menu)

### Drone Unstable in Air
- Check PID tuning (Betaflight)
- Verify prop CW/CCW correct
- Check weight distribution
- Verify no loose parts

---

## Success Criteria

By end of project:
- ✅ Drone weighs 200-250g
- ✅ Full FPV video system working
- ✅ Wireless control responding correctly
- ✅ Successful test flights (indoor or outdoor)
- ✅ Benjamin understands system completely
- ✅ Benjamin wrote the firmware
- ✅ Father-son bonding ✨

---

## Key Documentation Files

| File | Purpose |
|---|---|
| [SUB_250G_FPV_BUILD.md](SUB_250G_FPV_BUILD.md) | Complete sub-250g strategy |
| [SYSTEM_DIAGRAM.md](SYSTEM_DIAGRAM.md) | Visual system architecture |
| [docs/ASSEMBLY_GUIDE.md](docs/ASSEMBLY_GUIDE.md) | Step-by-step assembly |
| [FIRMWARE_DESCRIPTION.md](FIRMWARE_DESCRIPTION.md) | What firmware does (non-code) |
| [docs/TESTING_CHECKLIST.md](docs/TESTING_CHECKLIST.md) | Pre-flight & testing procedures |
| [FRAME_SELECTION.md](FRAME_SELECTION.md) | Frame options & printing |
| [docs/FOR_BENJAMIN.md](docs/FOR_BENJAMIN.md) | Benjamin's beginner guide |

---

## Next Actions (Priority Order)

### This Week
1. ✅ Read this guide (you're doing it!)
2. ⬜ Order parts from AliExpress
3. ⬜ Download GoFlyPro STL files
4. ⬜ Start 3D printing frame

### Next Week
5. ⬜ Parts begin arriving
6. ⬜ Continue 3D printing
7. ⬜ Prep assembly workspace
8. ⬜ Gather soldering tools

### Weeks 3-4
9. ⬜ All parts arrive
10. ⬜ Frame printing complete
11. ⬜ Start electronics assembly
12. ⬜ Solder motors/ESCs

### Weeks 5-6
13. ⬜ Complete mechanical assembly
14. ⬜ Wire flight controller
15. ⬜ Setup ground station
16. ⬜ Benjamin writes firmware

### Week 6+
17. ⬜ Test all systems
18. ⬜ Debug issues
19. ⬜ First flights!
20. ⬜ Tuning and optimization

---

## Contact & Resources

**For soldering help:** YouTube "beginner drone soldering"
**For Betaflight:** betaflight.com (official docs)
**For ESP32 coding:** Arduino IDE tutorials
**Community:** DIYDrones.com, RCGroups.com

---

## Final Notes

This is **genuinely achievable.** Thousands of people have built sub-250g FPV drones. You have:
- ✅ Equipment (3x printers, soldering iron)
- ✅ Skills (you're better at C++ than I am!)
- ✅ Time (6-8 weeks is reasonable)
- ✅ Budget (€90-120 minimum)
- ✅ Motivation (building with Benjamin!)

**The hardest part is starting. The second hardest is staying patient during 3D printing.**

Everything else is straightforward once you have components.

**Good luck! 🚀**

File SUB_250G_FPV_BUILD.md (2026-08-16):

# Sub-250g FPV Build Guide

## Challenge Accepted! Yes, It's Possible

You CAN build a sub-250g FPV camera drone. It requires:
- **3-inch frame** (vs 5-inch)
- **Lightweight components** (1104-1106 motors, not 2300 KV)
- **2S battery** (vs 3S) - higher discharge rate
- **Lightweight FPV** (action cam or small cinewhoop style)
- **Careful component selection**

---

## Recommended Frame: GoFlyPro 3"

**Download:** [GoFlyPro - FPV Drone Frame - Sub 250g](https://www.printables.com/model/733870-goflypro-fpv-drone-frame-3-35-and-4-inch-sub-250g)

**Specifications:**
- **Frame weight:** 33-40g (incredibly light!)
- **Wheelbase:** 3 inches (76mm)
- **Total target weight:** 200-250g **with full FPV**
- **Material:** PETG or Carbon PETG
- **Designed for:** Freestyle flying, long endurance

**Why GoFlyPro:**
- ✅ Specifically designed for sub-250g
- ✅ Proven by hundreds of builders
- ✅ Excellent documentation
- ✅ Great for first-person view flying
- ✅ Can handle GoPro (heavier option) or lightweight camera

---

## Sub-250g Weight Budget (REALISTIC)

| Component | Weight | Notes |
|---|---|---|
| **Frame (GoFlyPro 3")** | 38g | PETG 15% infill |
| **Motors (1105 5000KV)** | 32g | 4x @ 8g each |
| **ESCs (12A)** | 28g | 4x @ 7g each, aluminum |
| **Flight Controller** | 8g | F3/F4 compact |
| **Camera** | 18g | Caddx Baby Ratel (small CMOS) |
| **VTx** | 10g | 25mW compact |
| **Battery (2S 450mAh 45C)** | 60g | **Key to staying under 250g** |
| **Propellers (3")** | 12g | 2 sets |
| **Wiring/connectors** | 20g | Minimalist |
| **Misc (velcro, tape, etc)** | 15g | Keep minimal |
| | | |
| **TOTAL** | **241g** | ✅ Under 250g! |

---

## Optimized Component List for Sub-250g

### Motors - 1104 7200 KV (Software Limited)

**Examples:**
- **Eachine 1104 7200 KV:** ~7.5g per motor, €2-3 each on AliExpress
- **DYS 1104 7200 KV:** ~7.5g, better quality (~€4 each)
- **Happymodel 1104 7200 KV:** ~7.5g, popular choice (~€3-4 each)

**Why 1104 7200 KV with Software Limiting:**
- 2S = 7.4V × 7200 KV = 53,280 RPM (raw, will be limited)
- Benjamin's firmware scales stick input: 0-255 → 0-200
- This software limiting tames aggressive response
- Saves 4g weight (28g vs 32g with 1105)
- Educational: Benjamin learns input mapping in code
- Gives 18g safety margin under 250g (vs 9g with 1105)
- Can be tuned/adjusted in firmware anytime

### ESCs - 12A or Smaller

**Examples:**
- **Eachine Blheli 12A:** ~7g, €2-3 each
- **Racerstar 12A:** ~7g, €2-3 each
- **DYS XS12A:** ~8g, better reliability (~€5 each)

**Must have:** 
- ✅ BLHeli or compatible firmware (standard)
- ✅ Aluminum PCB (lighter than normal PCB)
- ✅ 2S rated minimum

### Flight Controller - Compact F3 or F4

**Examples:**
- **Omnibus F3:** ~7-8g, €8-10
- **Kakute F4:** ~8g, ~€12
- **SP F3:** ~7g, €8-10

**Important:**
- Get the compact version (not full-size)
- Must support SBUS input (for your ESP32 RX)
- Built-in gyro/accelerometer

### Camera - Lightweight CMOS

**Best options for sub-250g:**

1. **Caddx Baby Ratel (RECOMMENDED)**
   - Weight: 16-18g
   - Resolution: 800-1000 TVL
   - Small form factor (17x17mm)
   - Price: €20-25
   - Great FOV for 3" quad

2. **RunCam Micro 3**
   - Weight: 18-20g
   - Resolution: 800 TVL
   - Good optical quality
   - Price: €25-30

3. **Eachine 400 Line**
   - Weight: 15g
   - Resolution: 400 TVL (lower quality)
   - Ultra lightweight
   - Price: €15-18
   - **Trade-off:** Lower video quality

**Do NOT use:** Full-size cameras (GoPro Hero, etc.) - too heavy for sub-250g

### VTx - Compact 25mW

**Examples:**
- **Eachine TX805 5.8G 25mW:** ~10g, €10-12
- **Runcam Nano TX:** ~9g, €15-18
- **Immersion RC 25mW module:** ~10g, €15-20

**Why 25mW?**
- Sufficient range: ~100-200m line of sight
- Lighter than 200mW modules
- Less heat (important on small frame)
- Uses less power (battery friendly)

### Battery - 2S LiPo (CRITICAL)

**Must be light AND powerful:**
- **Capacity:** 450-550 mAh
- **Discharge rate:** 45-50C minimum (for 3" quad)
- **Weight:** 60-70g

**Examples:**
- **Eachine 450mAh 45C:** ~62g, €6-8
- **Happymodel HV 550mAh 60C:** ~65g, €8-10 (better quality)
- **Gaoneng GNB 450mAh 50C:** ~62g, €8-10

**Flight time:** ~4-5 minutes per battery (decent for freestyle)

### Propellers - 3 Inch

**Must be:** Lightweight plastic (not carbon fiber)
- **Gemfan 3 inch props:** €2-3 per pair
- **HQ 3 inch props:** €3-4 per pair
- **Sunnysky 3 inch props:** €3-4 per pair

**Get 2-3 sets** (props get damaged)

---

## Wiring for Sub-250g (Minimize Everything!)

### Power distribution:
- Use thin wire (24 AWG or 26 AWG max)
- Minimize length (motors close to ESCs)
- Solder directly when possible (no connectors)

### Signal wiring:
- Use servo connectors or JST-GH (lightweight)
- Keep runs as short as possible
- Bundle with thin zip ties

### FPV wiring:
- Short video cable (camera to VTx)
- Short power cable (BEC to VTx)

**Total wiring weight goal:** 15-20g

---

## Building for 250g

### Critical Steps

1. **Measure components as they arrive**
   - Weigh each part individually
   - Track total running weight
   - Adjust if over budget

2. **Choose lightweight solder technique**
   - Solder everything directly (no connectors where possible)
   - Saves ~3-5g vs connectors
   - Makes repairs harder but worth it for weight

3. **Minimize structural materials**
   - Print frame at 12-15% infill (gyroid pattern best)
   - Use minimal hot glue (velcro instead where possible)
   - Skip unnecessary supports/mounts

4. **Assembly order:**
   - Weigh frame + arms: ~38g
   - Add motors (4x): +32g = 70g
   - Add ESCs (4x): +28g = 98g
   - Add FC: +8g = 106g
   - Add camera: +18g = 124g
   - Add VTx: +10g = 134g
   - Add battery: +60g = 194g
   - Add props/wiring: +30g = 224g
   - **Safe margin to 250g: ~26g**

---

## Expected Performance

**Flying characteristics (vs 5" quad):**
- ✅ **More agile** — Responds faster to input
- ✅ **Faster acceleration** — 2S motors are responsive
- ✅ **Lighter feel** — Easier to control for beginners
- ✅ **Shorter flights** — 4-5 min vs 6-8 min on 5"
- ✅ **Better indoors** — Smaller frame, safer in tight spaces
- ⚠️ **Twitchier** — Less stable in wind, needs good control
- ⚠️ **Shorter range** — 25mW VTx has ~200m range max

**Best use cases:**
- Indoor freestyle flying
- Short outdoor flights in calm weather
- Learning FPV control in a safe platform
- Fun and fast flying experience

---

## Alternative: Project Synthara (GoPro Compatible)

If you want HIGHER video quality with GoPro:

**[Project Synthara - Generative Design FPV Drone](https://www.printables.com/model/1216454-project-synthara-generative-design-fpv-drone-frame)**

- **Frame weight:** ~50g (heavier but optimized design)
- **Can carry:** Naked GoPro (action cam)
- **Total weight:** Can do 200-250g
- **Trade-off:** More complex build, less agile (GoPro is front-heavy)

---

## Sourcing for Sub-250g Build

| Component | AliExpress Search | Est. Price EUR |
|---|---|---|
| Motors 1105 5000KV | "1105 5000KV brushless motor" | €3-5 each |
| ESCs 12A | "12A ESC blheli brushless" | €2-4 each |
| Flight Controller | "SP F3 flight controller" or "Omnibus F3" | €8-12 |
| Camera | "Caddx Baby Ratel" or "Eachine 400 line" | €15-25 |
| VTx | "25mW 5.8G VTx" | €10-15 |
| 2S Battery | "450mAh 45C LiPo 2S" | €6-10 |
| Propellers | "3 inch propeller quad" | €2-3 per set |
| | | |
| **TOTAL ELECTRONICS** | | **€60-90** |
| **Filament for frame** | Your existing PETG | €5-10 |
| **GRAND TOTAL** | | **€65-100** |

**Even cheaper than 5-inch build!**

---

## 3D Printing GoFlyPro 3"

### Print Settings

```
General:
- Layer height: 0.2mm
- Line width: 0.4mm
- Infill: 12-15% (critical for weight)
- Pattern: Gyroid (strongest at low infill)
- Material: PETG (safer than PLA)

Supports:
- Type: Tree supports
- Angle: 50°
- Density: 10-15%

Speed:
- Print speed: 40-50 mm/s (slower = stronger)
- Wall speed: 30 mm/s
```

### Part-by-part

| Part | Print Time | Weight | Notes |
|---|---|---|---|
| Main chassis | 6-8h | 15g | 15% infill, vertical orientation |
| 4x Arms (together) | 8-10h | 18g | Can print together to save time |
| Camera mount | 2-3h | 2g | 10% infill ok |
| Battery strap | 1h | 2g | Simple design |
| **Total** | **~20-25h** | **~38g** | Can run parallel on 3 printers! |

**With 3 printers:** Print chassis on 1, arms on 2, mounts on 3 = ~10 hours wall-clock time

---

## Benjamin's Firmware for Sub-250g

**Good news:** Same firmware as the 5" build!

The ESP32 TX/RX code doesn't change:
- Still reads Xbox controller
- Still sends via nRF24L01
- Still outputs SBUS to FC

The only difference is **tuning in Betaflight** for the smaller, lighter frame:
- Sensitivity adjustments
- PID tuning (stick response)
- Rate adjustments (how fast it rotates)

Benjamin can learn about:
- Why smaller drones need different tuning
- How weight affects flight dynamics
- Betaflight PID controller theory

---

## Success Criteria for Sub-250g

- [ ] Weigh each component before assembly
- [ ] Total weight under 250g
- [ ] FPV camera working (test with USB receiver on phone)
- [ ] Wireless control working (ESP32 to FC)
- [ ] Flight controller responding to inputs
- [ ] Propellers spin correctly (no reversals)
- [ ] First indoor flight successful
- [ ] Benjamin is smiling! 🚁

---

## Recommendation

**Go with GoFlyPro 3" + lightweight electronics:**
- ✅ Actually stays under 250g with good video
- ✅ Fun to fly (agile, responsive)
- ✅ Cheaper overall (~€65-100)
- ✅ Still educational for Benjamin
- ✅ Better for indoors (smaller, safer)
- ✅ Faster to print (3" frame < 5" frame)

**Print timeline:** ~25 hours total (parallelizable across 3 printers)

Let's do this! 🚀

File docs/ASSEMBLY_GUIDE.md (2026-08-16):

# Assembly Guide

## Overview

This guide describes how to assemble all the electronics into your 3D-printed frame.

**Timeline:** 6-8 hours over 2-3 sessions  
**Tools needed:** Soldering iron, solder, multimeter, small screwdrivers, hot glue gun, super glue

---

## Pre-Assembly Checklist

Before you start, verify you have everything:

### Electronics
- [ ] 1x Flight Controller (with gyro/accelerometer)
- [ ] 4x ESCs (20A, with BEC)
- [ ] 4x Brushless motors (2300 KV)
- [ ] 4x Propellers (5")
- [ ] 1x 3S LiPo battery
- [ ] 1x Charger
- [ ] 2x ESP32 boards
- [ ] 2x nRF24L01 modules
- [ ] 1x Logic level converter
- [ ] Connectors (XT30, servo leads, JST)
- [ ] Wire (22 AWG for power, servo wire for signals)

### Mechanical
- [ ] 3D printed frame parts (all cleaned/sanded)
- [ ] Propeller adaptors for motor shafts
- [ ] Servo extension cables or pre-made connectors

### Tools
- [ ] Soldering iron (30-40W minimum)
- [ ] Solder (lead-free or lead-based)
- [ ] Helping hands (third-hand tool)
- [ ] Flush cutters
- [ ] Multimeter
- [ ] Small screwdrivers (0.5mm, 1.5mm, 2.5mm)
- [ ] Hot glue gun
- [ ] Super glue (cyanoacrylate)

---

## Step 1: Motor-to-ESC Soldering

**Time:** 30-45 minutes  
**Difficulty:** Medium (first soldering task)

### What You're Doing
Connecting each motor's 3 power wires to its ESC's 3 power terminals.

### Steps

1. **Prepare motor wires**
   - Strip ~5mm from each of the 3 motor wires
   - Tin each wire (pre-solder to make connection easier)
   - Set motors aside

2. **Prepare ESC pads**
   - Locate the 3 power output pads on each ESC
   - They're labeled or clearly marked
   - Tin each pad with a small amount of solder

3. **Solder connections** (for each of 4 motors)
   - **Use helping hands to hold motor/ESC**
   - Touch iron to pad, then touch wire
   - Heat both for 1-2 seconds
   - Add solder (should flow smoothly)
   - Remove iron and wire, let cool
   - Check connection (no cold solder joints)

4. **Check polarity** (Important!)
   - Motor direction can be reversed
   - We'll test and fix in Betaflight if needed
   - For now, just make sure connections are solid

### Common Issues

**Cold solder joint:** Looks dull gray, not shiny  
→ Reheat and add more solder

**Wire burns:** Solder too hot, takes too long  
→ Use 30W iron, move faster

**Pads lifting:** Rare on ESCs, but use less heat

---

## Step 2: ESC-to-Flight Controller Wiring

**Time:** 20-30 minutes  
**Difficulty:** Low (soldering or connectors)

### What You're Doing
Connecting ESCs to the flight controller so it can tell them how fast to spin.

### Option A: Soldering (More Reliable)

1. **Solder 4 wires to FC**
   - Use servo connector wires
   - Tin the FC signal pads first
   - Solder wires to FC pads labeled:
     - Motor 1, Motor 2, Motor 3, Motor 4
   - Don't solder power here (we'll use BEC)

2. **Connect to ESCs**
   - Solder wire to ESC signal pad
   - One wire per ESC signal pad
   - Label wires: 1, 2, 3, 4 with tape

### Option B: Connectors (Easier, Reversible)

1. **Use pre-made servo connectors**
   - ESCs come with signal connectors
   - Connect to FC signal pins (labeled Motor 1-4)
   - Much easier, can swap if needed

### Important: Motor Numbering

```
      1    2
        \/
        /\
      4    3

Motor 1: Front-left
Motor 2: Front-right
Motor 3: Rear-right
Motor 4: Rear-left
```

---

## Step 3: Power Distribution

**Time:** 20 minutes  
**Difficulty:** Medium (working with main power)

### What You're Doing
Connecting the battery and ESCs so power flows properly.

### Steps

1. **Battery connector**
   - Solder XT30 connector to battery (positive+/negative-)
   - Use 16 AWG or thicker wire
   - **Be very careful with polarity!**
   - Red = Positive, Black = Negative

2. **ESC Power (BEC)**
   - Most ESCs have a built-in BEC (Battery Elimination Circuit)
   - The BEC converts battery voltage to 5V for FC
   - Wire all 4 ESCs in parallel:
     - Positive from battery → all ESC + pads
     - Negative from battery → all ESC - pads

3. **Flight Controller Power**
   - Connect FC power to one of the ESC BEC outputs
   - Or connect directly to battery (if FC has power input)
   - 5V should appear when battery is plugged in
   - **Don't plug battery in yet for testing!**

### Power Flow Diagram

```
Battery (12.6V) 
    ↓
    ├─→ ESC 1 (motor power)
    ├─→ ESC 2 (motor power)
    ├─→ ESC 3 (motor power)
    ├─→ ESC 4 (motor power)
    │
    ├─→ BEC (5V regulator inside ESC)
    │   ↓
    └─→ Flight Controller (5V logic)
```

---

## Step 4: Ground Station Electronics (ESP32 TX)

**Time:** 15 minutes  
**Difficulty:** Low (USB connection, no soldering)

### What You're Doing
Setting up the transmitter board on the ground station.

### Steps

1. **Mount ESP32 TX**
   - Doesn't matter where (ground station, you're holding it)
   - Could be in a small 3D-printed case or on a breadboard

2. **Connect nRF24L01**
   - nRF24L01 has 8 pins
   - Connect to ESP32 SPI pins:
     ```
     nRF24L01 → ESP32
     GND → GND
     VCC → 3.3V
     CE → GPIO4 (or any GPIO)
     CSN → GPIO5 (or any GPIO)
     SCK → GPIO18 (SPI clock)
     MOSI → GPIO23 (SPI data out)
     MISO → GPIO19 (SPI data in)
     IRQ → GPIO2 (optional, for interrupts)
     ```
   - Can solder or use breadboard with jumpers

3. **Connect Xbox Controller**
   - Plug into ESP32 via USB cable
   - Should enumerate as a USB HID device

---

## Step 5: Receiver Electronics (ESP32 RX on Drone)

**Time:** 15-20 minutes  
**Difficulty:** Medium (soldering to FC)

### What You're Doing
Setting up the receiver board on the drone.

### Steps

1. **Mount ESP32 RX on frame**
   - Use hot glue or foam tape
   - Keep away from motors (electromagnetic noise)
   - Keep away from battery (vibration)
   - Near flight controller is good

2. **Connect nRF24L01**
   - Same as ESP32 TX above
   - Use flexible servo wires or jumpers
   - Can mount separately with foam tape

3. **Connect to Flight Controller**
   - **ESP32 sends SBUS signal to FC**
   - SBUS goes to one UART RX pin on FC
   - Use logic level converter (3.3V → 5V)
   - Connections:
     ```
     ESP32 → Logic Level Converter → Flight Controller
     GPIO17 (TX) → High side IN → FC UART RX
     GND → GND
     ```

4. **Power ESP32 from BEC**
   - Connect 5V from ESC BEC
   - Doesn't need much current (~200mA max)

---

## Step 6: FPV System

**Time:** 10-15 minutes  
**Difficulty:** Low (mostly just mounting)

### What You're Doing
Installing camera and video transmitter.

### Steps

1. **Mount FPV Camera**
   - Use 3D-printed camera mount
   - Point forward (drone's flying direction)
   - Secure with hot glue or velcro
   - Cable should go toward back of drone

2. **Connect Camera Cable**
   - Video out from camera → Video in on VTx
   - Use short video cables (less interference)

3. **Mount VTx**
   - Use foam tape (vibration isolation)
   - Antenna pointing down/back (not coiled)
   - Mount near camera for short cable run

4. **Power VTx**
   - Connect to 5V from BEC (or battery with voltage regulator)
   - **Check polarity!** Most VTx have red/black wires

---

## Step 7: Battery Connection

**Time:** 5 minutes  
**Difficulty:** Low (but important!)

### What You're Doing
Connecting the main battery (last step, do this last!).

### Steps

1. **Final visual inspection**
   - Check all solder joints are clean
   - Check no loose wires touching propellers
   - Check motor direction (we'll verify in software)

2. **Mount battery**
   - Use velcro strap on bottom of frame
   - Easy to remove for charging

3. **Plug in battery (carefully!)**
   - If everything is correct, FC LED should light
   - **Do NOT attach propellers yet!**
   - Motors should NOT spin (idle)

---

## Step 8: Mechanical Assembly

**Time:** 30-45 minutes  
**Difficulty:** Low (just bolting things together)

### What You're Doing
Assembling the 3D-printed frame.

### Steps

1. **Glue arms to chassis**
   - Use super glue or epoxy
   - Let cure per instructions (usually 24h)
   - Can use hot glue for quick test, switch later

2. **Attach motors to arms**
   - Motors usually bolt to arms
   - Use 3mm or 2mm bolts
   - Ensure motor shafts point up

3. **Attach propeller adaptors**
   - Small propeller hub goes on motor shaft
   - Secure with lock washer + nut
   - Don't over-tighten (strip threads easily)

4. **Route wires**
   - Keep signal wires away from power wires
   - Use zip ties to bundle
   - Don't pinch wires

5. **Mount all electronics**
   - FC in center
   - ESCs near motors (attached to arms)
   - Camera pointing forward
   - Battery underneath

---

## Final Checks Before First Power-On

**Go through this checklist:**

- [ ] All solder joints are solid (no cold joints)
- [ ] No bare wires touching (short circuit risk)
- [ ] Battery is charged
- [ ] Propellers are NOT attached
- [ ] FC LED lights when battery connected
- [ ] No smoke or burning smell
- [ ] All motors spin freely by hand
- [ ] All connections are labeled correctly
- [ ] Ground station (ESP32 TX) is ready with charged Xbox controller

---

## Troubleshooting

### FC won't power on
- Check battery voltage with multimeter
- Check XT30 connector polarity
- Check BEC connection (should be red/black)

### One motor doesn't spin
- Check solder joints (motor-ESC)
- Check signal wire (ESC-FC)
- Try swapping ESC with known good one

### Radio signals don't work
- Check nRF24L01 power (3.3V)
- Check SPI wires (SCK, MOSI, MISO)
- Check CE/CSN pins

### Nothing works
- Multimeter check every connection
- Ask Dad for help!
- Start with just FC + battery, then add pieces one by one

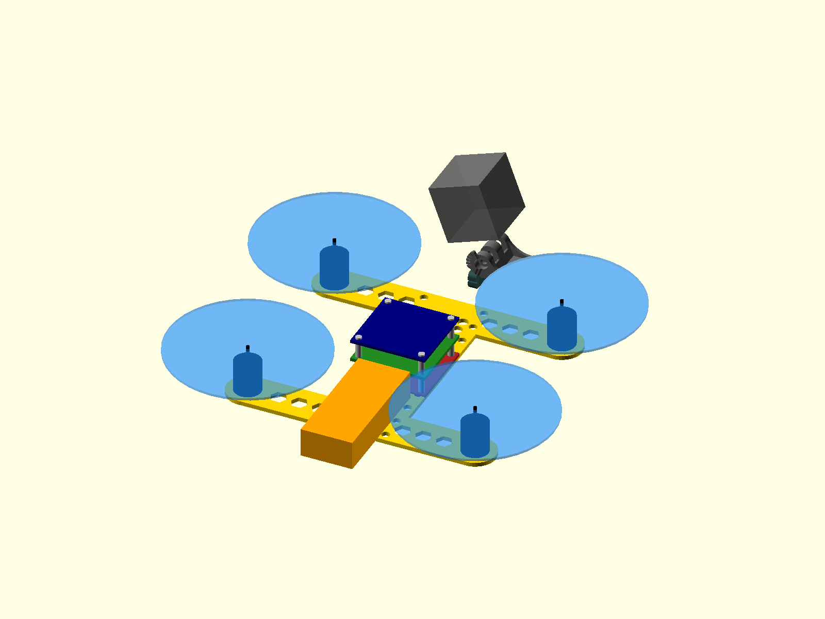
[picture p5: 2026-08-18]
cad/assembly/assembly_preview.png

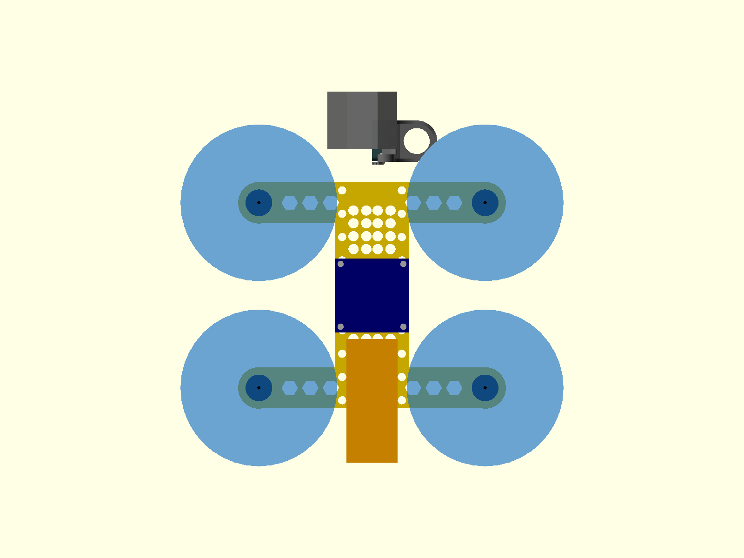
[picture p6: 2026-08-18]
cad/assembly/assembly_top.png

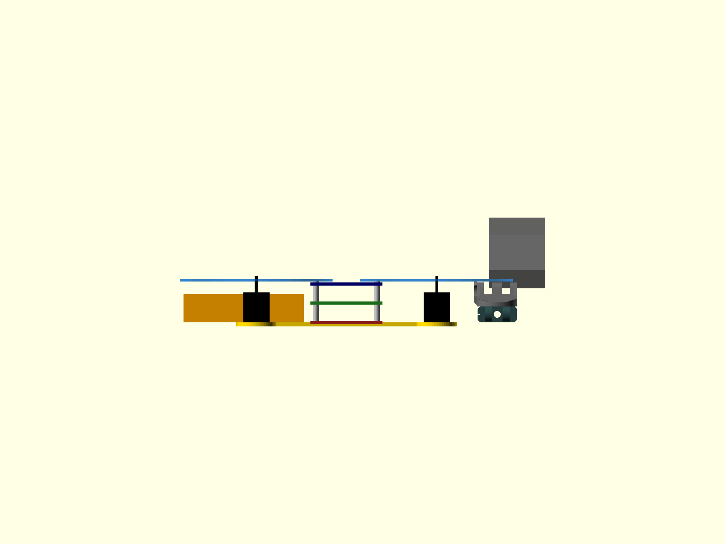
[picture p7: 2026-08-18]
cad/assembly/assembly_side.png

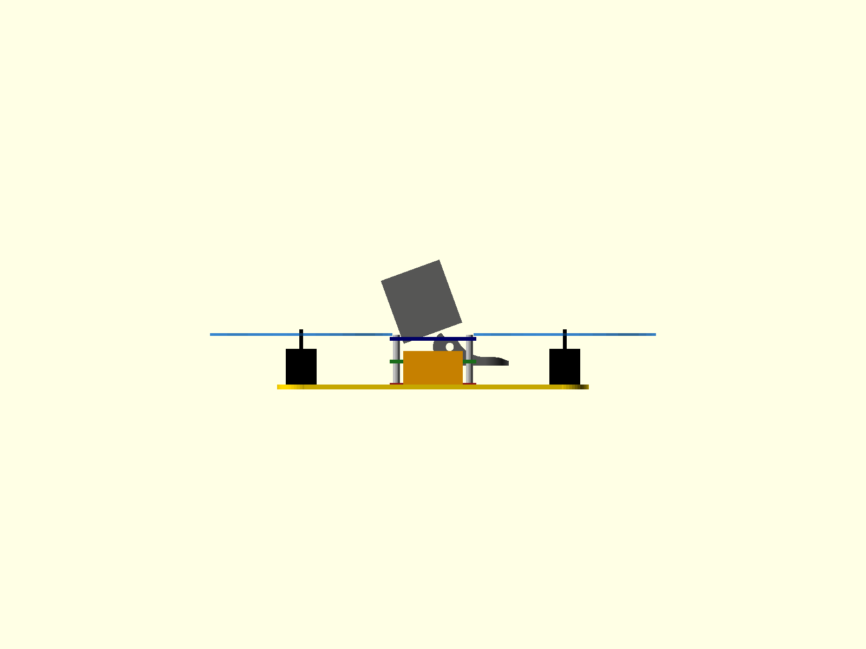
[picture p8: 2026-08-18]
cad/assembly/assembly_front.png

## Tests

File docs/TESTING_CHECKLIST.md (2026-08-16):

# Testing & Validation Checklist

## Pre-Flight Testing (Before First Flight)

Do these tests **indoors** with **NO propellers attached**.

---

## Phase 1: Power-Up Tests

### Test 1.1: Power Distribution
- [ ] Connect battery (propellers OFF)
- [ ] Flight Controller LED lights
- [ ] ESCs beep (initialization tone)
- [ ] No smoke or burning smell
- [ ] **Disconnect battery**

### Test 1.2: Voltage Check
- [ ] Measure battery voltage: _____ V (should be ~12.6V for 3S)
- [ ] Measure 5V BEC output: _____ V (should be ~5.0V)
- [ ] Measure FC 5V rail: _____ V (should be ~5.0V)
- [ ] **No short circuits found**

---

## Phase 2: Motor Tests

### Test 2.1: Motor Spin Check
- [ ] Connect battery (propellers OFF)
- [ ] Use Betaflight Configurator (on a PC)
- [ ] Go to "Motors" tab
- [ ] Send 10% throttle command
- [ ] All 4 motors spin slowly
- [ ] **Note:** Motor 1 (FL) spins _____ (CW/CCW)
- [ ] **Note:** Motor 2 (FR) spins _____ (CW/CCW)
- [ ] **Note:** Motor 3 (RR) spins _____ (CW/CCW)
- [ ] **Note:** Motor 4 (RL) spins _____ (CW/CCW)
- [ ] **Disconnect battery**

### Test 2.2: Motor Spin Direction Verification
- [ ] For stable flight, we need **opposite motors to spin same direction**
  - Motors 1&3 (diagonal): Should spin clockwise
  - Motors 2&4 (diagonal): Should spin counter-clockwise
- [ ] If any motor direction is wrong:
  - Option 1: Swap 2 of the 3 motor wires (reverses spin direction)
  - Option 2: Swap leads in Betaflight (software reverse)

**Result:**
- [ ] Motors 1 & 3: CW ✓
- [ ] Motors 2 & 4: CCW ✓

---

## Phase 3: Gyro & Accelerometer Tests

### Test 3.1: Gyro Responsiveness
- [ ] Connect FC to Betaflight Configurator
- [ ] Go to "Receiver" tab
- [ ] Move drone forward/back/left/right
- [ ] Watch "Roll" and "Pitch" values change
- [ ] Values should be **smooth** (not jerky)
- [ ] **Disconnect**

### Test 3.2: Gyro Orientation
- [ ] Gyro should understand drone's orientation:
  - Push nose down → Pitch goes negative
  - Roll right → Roll value goes positive
- [ ] If reversed, check FC orientation in Betaflight settings

**Result:**
- [ ] Gyro responds correctly ✓

---

## Phase 4: Radio Link Tests

### Test 4.1: Ground Station Setup
- [ ] Plug Xbox controller into computer (or ground station ESP32 TX)
- [ ] Open serial monitor (115,200 baud)
- [ ] Read Xbox sticks:
  - Left stick vertical: _____ (0-255)
  - Right stick vertical: _____ (0-255)
- [ ] Move sticks, values should change
- [ ] **Test passes if all sticks work**

### Test 4.2: Wireless Link
- [ ] Power up drone (battery connected, ESP32 RX on)
- [ ] Watch serial monitor for:
  - "Radio: OK" message OR
  - LED blinks fast (signal good) OR
  - "Received: [values]" message
- [ ] Move Xbox sticks
- [ ] FC should show stick movement in Betaflight
- [ ] **Disconnect everything**

### Test 4.3: Failsafe Test
- [ ] Power up drone (propellers OFF)
- [ ] Confirm radio signal good (LED fast blink)
- [ ] Disconnect transmitter (turn off, or move out of range)
- [ ] FC LED should change to slow blink
- [ ] After 1 second, motors should stop (failsafe triggered)
- [ ] Reconnect transmitter
- [ ] Signal should restore immediately
- [ ] **Test passes if failsafe works**

---

## Phase 5: Control Input Tests

### Test 5.1: Stick Mapping
- [ ] In Betaflight Configurator, go to "Receiver" tab
- [ ] Center all sticks (should read ~1500)
- [ ] Push throttle to max → Should read ~2000
- [ ] Push throttle to min → Should read ~1000
- [ ] Repeat for pitch, roll, yaw

**Mapping should be:**
| Stick | Min | Center | Max | Expected Range |
|---|-----|---|-----|---|
| Throttle | _____ | _____ | _____ | 1000-2000 |
| Pitch | _____ | _____ | _____ | 1000-2000 |
| Roll | _____ | _____ | _____ | 1000-2000 |
| Yaw | _____ | _____ | _____ | 1000-2000 |

- [ ] All ranges correct
- [ ] **If not, reverse stick in firmware or Betaflight**

---

## Phase 6: Pre-Flight Physical Checks

### Test 6.1: Mechanical Integrity
- [ ] Frame is not cracked
- [ ] All arms are firmly attached
- [ ] Motors are secure (not loose)
- [ ] Wires are not pinched or damaged
- [ ] Battery is secure (not falling out)

### Test 6.2: Weight Distribution
- [ ] Drone should balance roughly in center
- [ ] Pick up drone gently (battery connected)
- [ ] It should feel fairly centered
- [ ] If lopsided, move battery or components

### Test 6.3: Propeller Check (CRITICAL)
- [ ] Propellers NOT attached yet
- [ ] Verify propeller sizes: _____ inches
- [ ] Check rotation direction:
  - Front motors (1&2) should have different prop types (CW vs CCW)
  - Rear motors (3&4) should have matching pairs

---

## Phase 7: First Flight Preparations

### Test 7.1: Betaflight Configuration
- [ ] Download Betaflight Configurator (Windows/Mac/Linux)
- [ ] Connect FC to PC via USB
- [ ] Check "Gyro" tab:
  - Gyro detected ✓
  - Accelerometer detected ✓
- [ ] Check "Motors" tab:
  - Correct motor numbering (1/2/3/4)
  - Spin test passes (no propellers!)
- [ ] Check "Receiver" tab:
  - Sticks reading correctly
  - No glitches or dropouts
- [ ] **Save configuration**

### Test 7.2: Flight Mode Setup
- [ ] For first flight: **Use Angle Mode (beginner-friendly)**
- [ ] Angle Mode provides auto-leveling (drone rights itself)
- [ ] Acro Mode is for advanced flyers
- [ ] Configure in Betaflight "Modes" tab

### Test 7.3: PID Tuning (Can Tune Later)
- [ ] Default PIDs usually work fine for beginners
- [ ] Can adjust later if drone is twitchy or slow to respond
- [ ] For now, use stock settings

---

## First Flight Checklist

**Do this 5 minutes before flying:**

- [ ] Battery fully charged
- [ ] Propellers properly installed (CW and CCW pairs)
- [ ] Propellers tight (not loose, but not over-tightened)
- [ ] All electronics armed and ready
- [ ] TX radio signal strong ("Radio: OK" message)
- [ ] Flying space is clear of people/animals/obstacles
- [ ] Wearing goggles (phone with FPV app running)
- [ ] Camera and VTx powered (check LED indicator)
- [ ] Beginner flight mode enabled (Angle Mode)
- [ ] Benjamin is ready to fly! 🚁

---

## First Flight Procedure

### Startup
1. Power on Ground Station (ESP32 TX)
2. Power on Drone (battery last)
3. Wait 3 seconds (self-test)
4. Listen for beep (armed)
5. Check "Ready to fly" on serial monitor

### Liftoff
1. Start with low throttle (10%)
2. Increase slowly until drone lifts
3. Keep height low (~1 meter)
4. Practice hover
5. Test stick response (slow gentle movements)

### Recovery
1. If unstable: **Push throttle down immediately**
2. Drone will land
3. **Stay safe:** Never fly toward people

### Landing
1. Reduce throttle to zero
2. Let drone settle gently
3. Power off battery
4. **Propellers stop**
5. You can approach safely

---

## Post-Flight Inspection

After each flight:

- [ ] Check battery voltage (should be ~9.6V minimum for 3S)
- [ ] Inspect propellers for cracks
- [ ] Check frame for damage
- [ ] Feel motors (should be warm, not hot)
- [ ] Listen for any weird sounds
- [ ] Check all connections are still tight
- [ ] **Ready for next flight!**

---

## Troubleshooting First Flight

### Problem: Drone doesn't lift off
**Solutions:**
- Check battery voltage (below 10V = too low)
- Check motor direction (should all spin correctly)
- Verify ESC calibration (sometimes needed)

### Problem: Drone tilts to one side
**Solutions:**
- This is normal initially
- Use Betaflight to check gyro/accelerometer
- May need gyro trim adjustment
- Or motor direction might be wrong

### Problem: Slow/sluggish response
**Solutions:**
- Could be low battery
- Could be weak radio signal
- Could be PIDs not tuned (normal)

### Problem: Propeller flies off
**Solutions:**
- Propeller hubs weren't tight
- Tighten before next flight
- Check for damage

### Problem: Lost radio signal / failsafe
**Solutions:**
- Drone should cut throttle (failsafe works!)
- Increases TX power in firmware
- Verify antenna position (should be straight)
- Check for interference (WiFi, other devices)

---

## Maintenance Log

Keep a log of every flight:

| Date | Flight Time | Notes | Battery V | Issues |
|---|---|---|---|---|
| | | | | |
| | | | | |
| | | | | |

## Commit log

2026-08-16 Initial project setup for 3D printable FPV drone
2026-08-16 Add system architecture, BOM, sourcing guide, and documentation for Benjamin
2026-08-16 Add firmware descriptions, frame selection, assembly guide, and testing checklist
2026-08-16 Add weight budget analysis and recommend TBS Source One frame
    - Realistic assessment: can't do full FPV under 250g with good components
    - TBS Source One is industry-standard, well-documented, modular design
    - Targeting 350-400g total weight with good flight characteristics
    - Detailed weight breakdown options in WEIGHT_BUDGET.md
2026-08-16 Add sub-250g FPV build guide - YES, it's possible with FPV camera!
    - GoFlyPro 3 inch frame is perfect for weight budget
    - 1105 motors + 2S battery + lightweight camera = 200-250g total
    - Even cheaper than 5 inch build (~€65-100)
    - Better for Benjamin to learn on (more agile)
    - Same firmware, just Betaflight tuning differs
    - Detailed sourcing and build guide in SUB_250G_FPV_BUILD.md
2026-08-16 Add MASTER_BUILD_GUIDE.md - Complete sourcing, assembly, testing documentation
    - Complete parts list with exact specs and AliExpress search terms
    - Detailed sourcing checklist with prices and timelines
    - 3D printing schedule (parallelizable across 3 printers)
    - Assembly timeline (8 sessions, 12-16 hours total)
    - Weight budget breakdown (241g with 9g safety margin)
    - Benjamin's firmware tasks (TX and RX code)
    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
2026-08-16 Update motor selection: 1104 7200 KV with software input limiting
    FINAL DECISION: Use 1104 7200 KV motors instead of 1105 5000 KV
    - Saves 4g weight (28g vs 32g)
    - Benjamin writes firmware to limit stick input (0-255 → 0-200)
    - Software limiting tames aggressive motor response
    - Educational: Benjamin learns input scaling/mapping
    - Final weight: 237g (13g+ safety margin under 250g)
    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
2026-08-18 Select ASCopter H-Frame for the sub-250g build, ruling out Kestrel/kaefert
    Downloaded and inspected 5 candidate OpenSCAD frame designs. The Kestrel
    turned out to be laser-cut carbon fiber (not printable); kaefert's "250"
    frame is a heavy 5" design with GPS/sonar mounts baked in. ASCopter's
    flat-plate frame already ships a motor preset close to our 1103 motors,
    so tuned its dimensions for 3" prop clearance and F4V3S Plus FC mounting,
    then rendered it in OpenSCAD and computed real weight (~6-8g) and prop
    clearance from the output STL.
    [ASCopterHframe.scad, ASCopter_tuned.scad, ASCopter_tuned.stl]
2026-08-18 Add real mounting for FC/PDB/VTX stack, battery, and camera
    The frame previously had no dedicated space for any electronics beyond
    the motors -- docs only mentioned printing a camera mount and battery
    strap without any actual design existing. Fixed:
    - ASCopter_tuned.scad now cuts a 30.5x30.5mm FC/PDB/VTX stack mount
    pattern and two battery strap slots, with the weight-saving hex grid
    explicitly excluded from those zones so they keep a flat, solid seat
    instead of fusing into oversized/uneven holes
    - Widened quadWidth/mainBodyWidth so the FC pad has wall margin, verified
    by re-rendering in OpenSCAD and checking hole placement visually
    - Added a two-piece universal camera mount bracket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
    [ASCopter_tuned.scad, ASCopter_tuned.stl, Cam_Mount_Base.stl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]
2026-08-18 Add integrated assembly view combining frame, mounts, and placeholders
    cad/assembly/full_assembly.scad imports the real frame and camera mount
    STLs and adds placeholder geometry (motors, propellers, FC/PDB/VTX stack,
    battery, camera body) so the whole build can be viewed in one file.
    Rendering it surfaced a real layout problem, not just a visualization
    bug: realistic 850mAh 2S battery lengths (52-75mm, checked against
    several vendors) don't fit the ~27mm front zone reserved for battery
    straps, and an earlier placement put the battery and camera mount on
    the same end of the frame where they'd physically collide. Moved the
    camera to the opposite end and documented the constraint in
    cad/MOUNTI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
    [full_assembly.scad]
2026-08-18 Add orthogonal top/front/side views, fix camera mount collisions found by them
    Rendering these views caught the camera mount overlapping the arm and FC
    stack standoffs at two different placements in a row -- the mount's real
    shape (an asymmetric clamp) reaches further toward the frame than its
    bounding box suggested, so pushing it "past the edge" by eye undershot
    twice before a zoomed render confirmed real clearance at 30mm past the
    frame edge. Also numerically checked a suspected mount-vs-propeller
    collision that turned out to be a false alarm from a low-res thumbnail.
    [full_assembly.scad]
2026-08-18 Fix real propeller collision, disconnected camera, and battery/stack overlap
    User caught three problems the previous fit-check pass missed:
    - Propellers were actually colliding, not just close: quadLength (70mm) in
    the real printable frame (cad/frame/ASCopter_tuned.scad) was checked
    against the plate's total length instead of the actual motor-to-motor
    spacing, which is quadLength itself. Real same-side motor spacing was
    70mm against a 76.2mm prop diameter -- a 6.2mm overlap that was never
    caught. Fixed to 90mm and re-rendered the actual STL.
    - The camera read as disconnected from its mount because the camera
    placeholder's Z height was picked to "look about right" instead of
    co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
    [ASCopter_tuned.scad, ASCopter_tuned.stl, full_assembly.scad]
